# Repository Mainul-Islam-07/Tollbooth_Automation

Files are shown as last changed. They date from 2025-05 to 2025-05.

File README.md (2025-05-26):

#  🚧 Tollbooth_Automation
## ℹ️ Overview
Developed an automated tollbooth system capable of managing vehicle access efficiently, securely, and intelligently using a state machine–based control architecture.
The core logic is modeled as a finite state machine, enabling the system to transition between different operational modes depending on real-time triggers like camera input, payment status, vehicle movement, or override commands.
## 🌟 Highlights

### Microcontroller 💻
STM32F103C8t6 is used as the microcontroller.

### Ethernet Communication 🌐
Wiznet W5500 is used for Ethernet communication with the computer.

### UART Communication 🔄
Two UART communication interfaces (One of them is for debugging).

## ⚙️ Features 
### Vehicle Detection (Entry) 🚗
Detection of an approaching vehicle using inductive loop coils installed on the entry lane.

### Automated Boom Barrier Control 🚧
The boom barrier is raised or lowered based on toll payment status and vehicle position, ensuring only authorized passage.

### Vehicle Detection (Exit) 🚙
Detection of a car leaving the toll area is also handled via loop coils on the exit side.

### Car Exit Confirmation via IR Sensor 🌟
An IR sensor provides an additional check to confirm that the car has left the toll zone properly.

### Siren Control for Violations 🚨
A siren is triggered in case of illegal car passage (e.g., unpaid exit) and turned off after resolution or proper payment.

### TCU Breach Detection 🔒
The system monitors for unauthorized access or tampering with the Toll Controller Unit (TCU) and issues alerts on breach.

### Lane Operation Light Control 💡
The system manages lane indicator lights, guiding operators and drivers based on system state (e.g., red/green lights for status).

### Overhead Light Control 🌙
Overhead lighting at the booth is automatically controlled depending on operational mode or time of day.

### Additional Device Control (x3) ⚙️
Provision to control three additional AC or DC devices, configurable for future expansion (e.g., fan, display board, heater).

### PC Power Control (Upcoming) 💻
Planned feature to automatically turn the PC on/off based on toll activity or scheduled requirements. (Not yet implemented)

### Event Logging with External RTC (Upcoming) 🕰️
Future capability to log system events and state changes using a Real-Time Clock (RTC) module for time-stamped data. (Not yet implemented)

## Other Important aspects:

### Wiznet Interrupt-Based Communications 

### UART DMA Interrupt-Based Communication 

### Optocoupler-Based Input/Output for Isolation

### Encrypted Communication 🔐 (Not implemented yet)

## LED Board Config

Led Baord
 
## 🔁State Machine



## 🔧 Input/Output Circuit Diagram (Not Updated - Need Fix)

IO

## PCB Sample Image

TCU

## Proteus Simulation Sample (Not Updated - Need Fix)

abcde

# ICPS Header Connection between PCBs

Issues09

# Relay Board Pinout
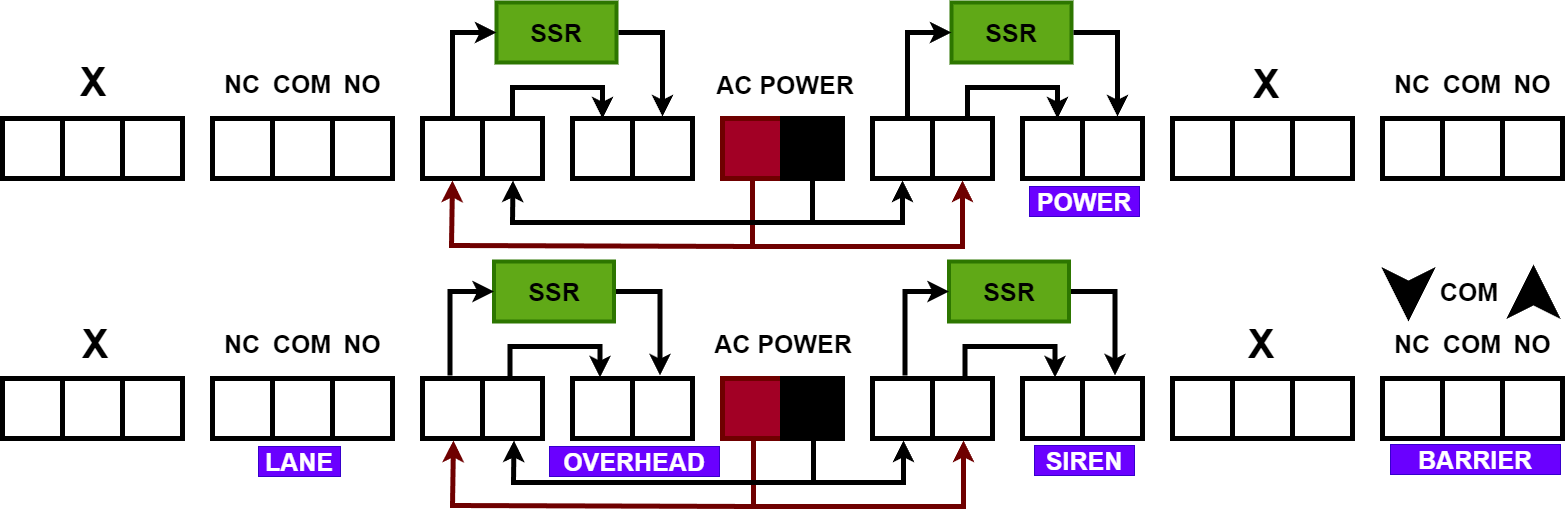
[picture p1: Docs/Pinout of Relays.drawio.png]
Relay Pinout


## ⬇️ Installation

Download and Install STM32CubeIDE from https://www.st.com/en/development-tools/stm32cubeide.html

Download and Install Hercules from https://www.hw-group.com/software/hercules-setup-utility

Download and Install Serial Debugger Assistant from https://apps.microsoft.com/detail/9nblggh43hdm?hl=en-US&gl=US

## Setup

1) Download the zip or fork and then clone to a local directory
2) Import the folder as a project in STM32CubeIde
3) Plug the mcu using st-link v2 where,

| MCU Pin (90° Bent) | Corresponding Pin on ST Link V2 |
|---|---|
| 3V3 (90 Degree Bent) | 3V3 |
| GND (90 Degree Bent) | GND |
| SWDIO (90 Degree Bent) | SWDIO |
| SCLK (90 Degree Bent)  | SCLK |

Like this,

Config

Then, plug the usb type A of ST-LINK V2 to Computer.

4) Press "Run" in the CubeIDE. Done!

# PCB PROBLEMS / SOLUTIONS / CONCERNS

2nd Iteration PCB is not finalized yet.

## TOLL CONTROLLER UNIT

1) SCLK And RST Connection from W5500 to MCU is manually swapped using wires. It should be fixed in next PCB design Iteration.
2) TX and RX connection from both UARTs is manually swapped using wires. The ususal way is UART TX > MCU TX and UART RX > MCU RX. To be fixed in the nextIteration.

Issues
Issues01

3) Since less current flow at Input, 1k ohm resistors attached at all of the 4 inputs in replaced by wire (shorting). Now the optocoupler responses any voltage from 6V. To be fixed in next iteration.
4) Voltage divider resistors are changed from 22k and 33k to 470 and 1k ohm for all inputs. It provides proper input to the mcu pins. To be fixed in next iteration.

Issues02
Issues03

5) All 470 ohm connected from MCU to Relay signal input side is manually shorted. This is done for proper signal sending. To be fixed in next iteration.
6) Voltage divider resistors are changed from 22k and 33k to 33k and 100k for All UART RX. To be fixed in the next iteration.
   
Issues04
Issues05

8) w5500 needs to be powered using a regulator from 5V to 3.3V. To be Fixed in next iteration.

## RELAY BOARD

1) The resistor after 470 ohm should not be used. It should be kept open. To be fixed in the next iteration.
2) A pullup of 10k is given from 12 volt to base of bc557 in such a way that it can be made 0V / 12V when needed. To be fixed in the next iteration.

Issues06
Issues07

3) Pulldown resistor is given of 100k ohm resistors.

Issues08

## LED BOARD

1) 1k ohm is connected to every signal end of mosfet used for powering RGB LED. Otherwise biasing issues emerge. To be fixed in the next iteration.
   
Issues09

2) Led that are powered by mcu directly should be equiped with less value resistor, lets say 100ohm. Applicable for Camera_Trigger, Payment and Ping LEDs.

# CODE PROBLEMS / SOLUTIONS / CONCERNS

1) Individual Flags for sensor update should be implemented in next iteration. 
2) CMD_NO_COMMAND should replace CMD_RESET as default outcome from processcommand.

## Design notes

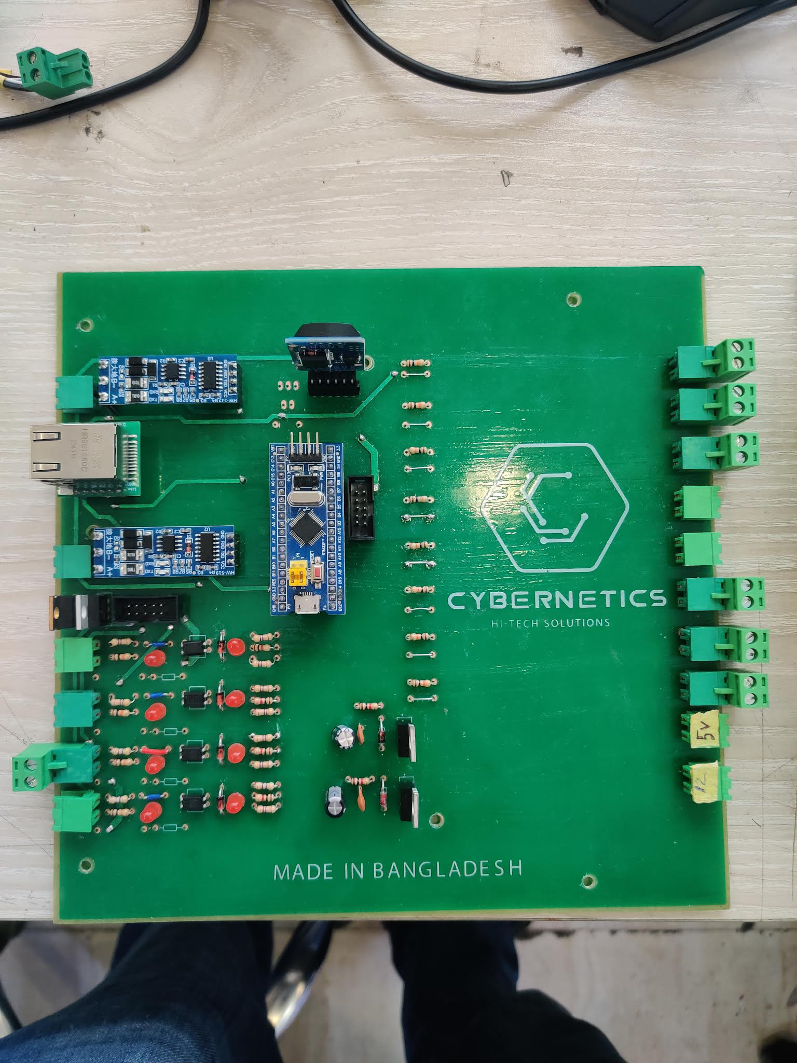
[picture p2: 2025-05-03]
Docs/TCU.jpg

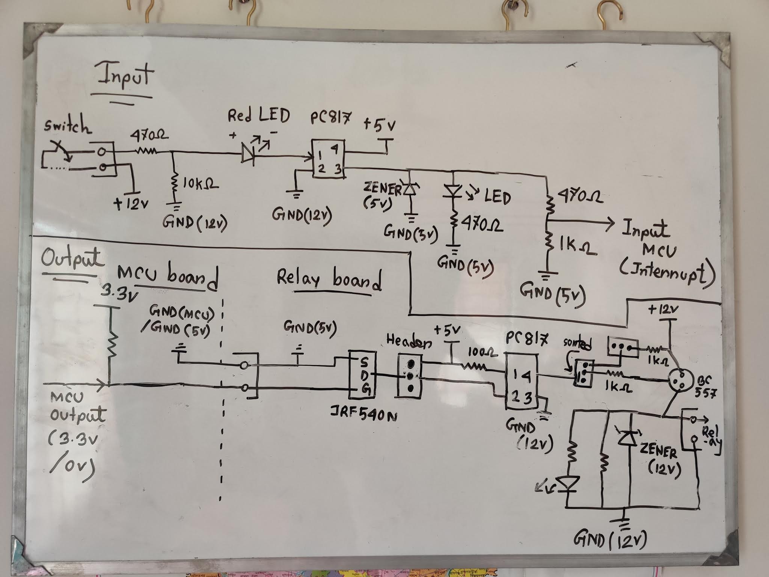
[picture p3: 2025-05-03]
Docs/IO.jpg

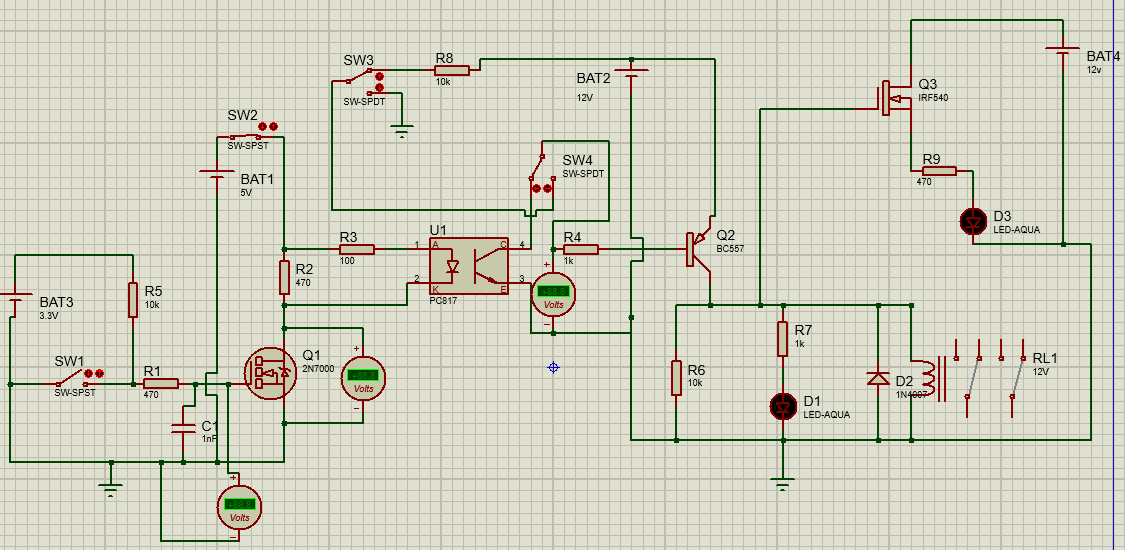
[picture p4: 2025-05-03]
Docs/Proteus Simlation.png

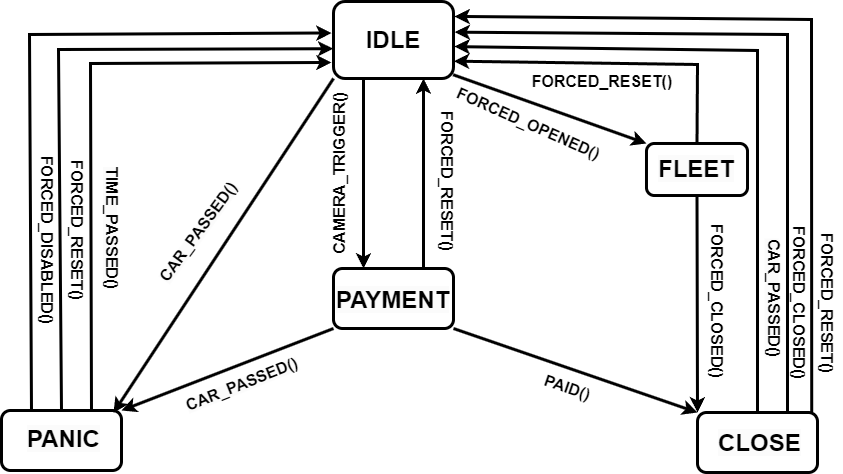
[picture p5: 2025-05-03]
State_Machine/State Diagram.png

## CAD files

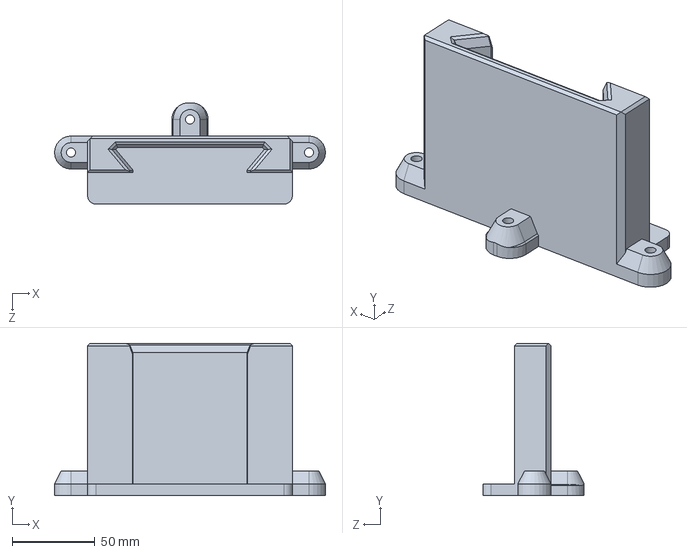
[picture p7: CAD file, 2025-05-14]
3D_Print/TCU LED board enclosure/Dove tail slot.SLDPRT
163.8 x 92.0 x 61.2 mm

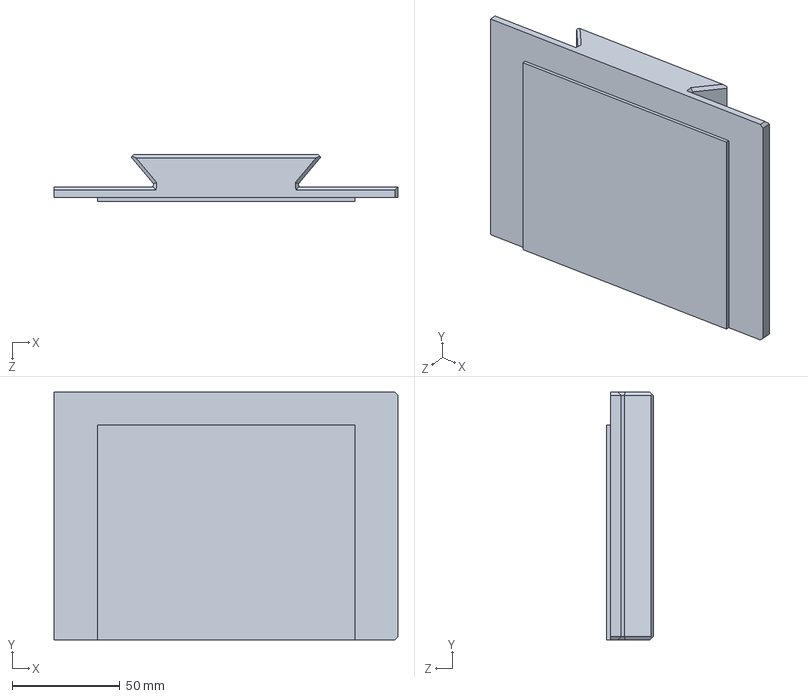
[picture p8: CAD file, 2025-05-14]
3D_Print/TCU LED board enclosure/Dove Tail.SLDPRT
159.7 x 115.0 x 21.7 mm

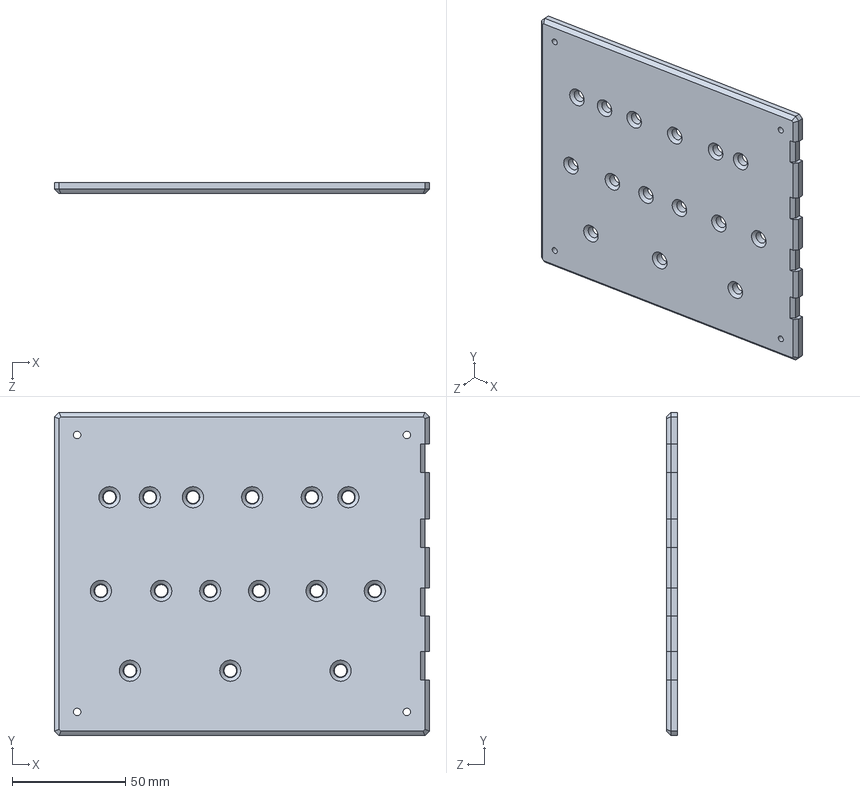
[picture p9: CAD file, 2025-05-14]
3D_Print/TCU LED board enclosure/Box top.SLDPRT
165.5 x 142.8 x 5.00 mm

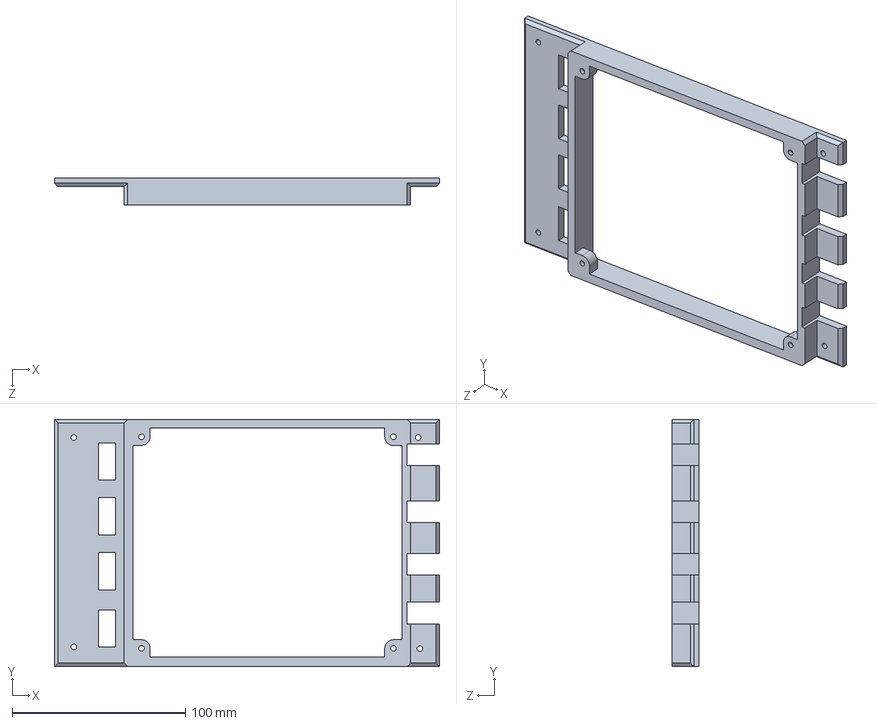
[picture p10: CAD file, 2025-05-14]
3D_Print/TCU LED board enclosure/Box Mid.SLDPRT
222.5 x 142.8 x 15.8 mm

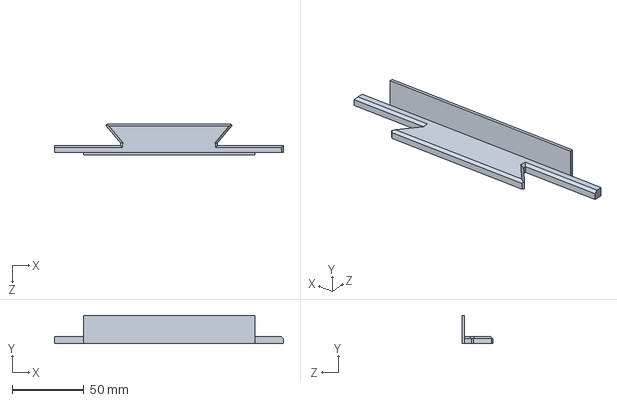
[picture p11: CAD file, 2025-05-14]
3D_Print/TCU LED board enclosure/Dove Tail mod.SLDPRT
159.7 x 19.7 x 21.7 mm

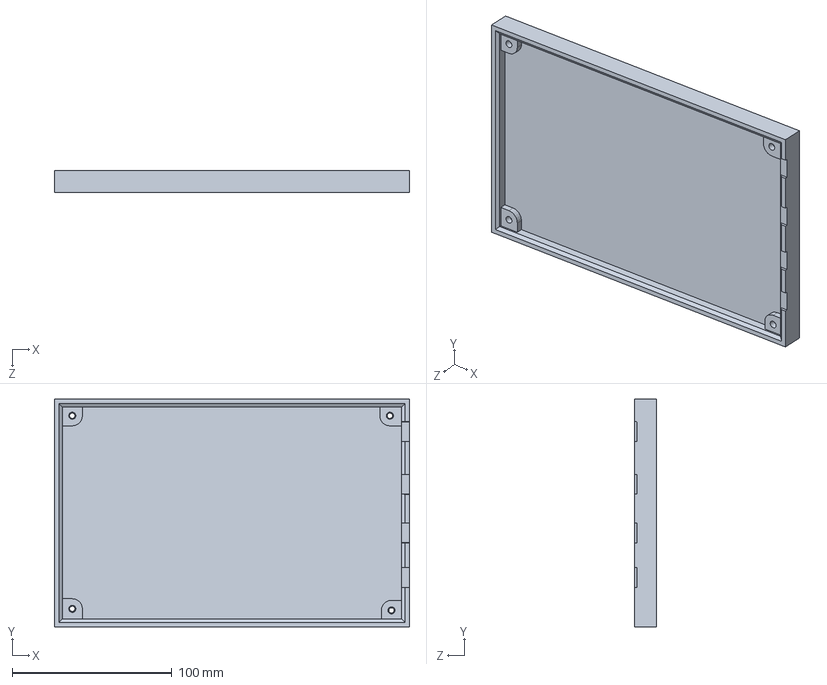
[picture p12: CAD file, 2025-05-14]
3D_Print/TCU LED board enclosure/Box base.SLDPRT
222.5 x 142.8 x 13.6 mm

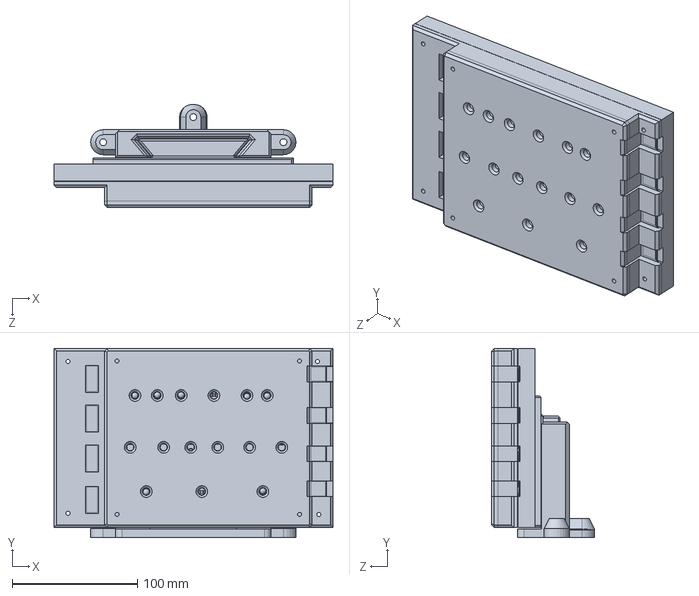
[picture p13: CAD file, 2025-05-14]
3D_Print/TCU LED board enclosure/LED_BOARD.SLDPRT
222.5 x 150.8 x 82.0 mm

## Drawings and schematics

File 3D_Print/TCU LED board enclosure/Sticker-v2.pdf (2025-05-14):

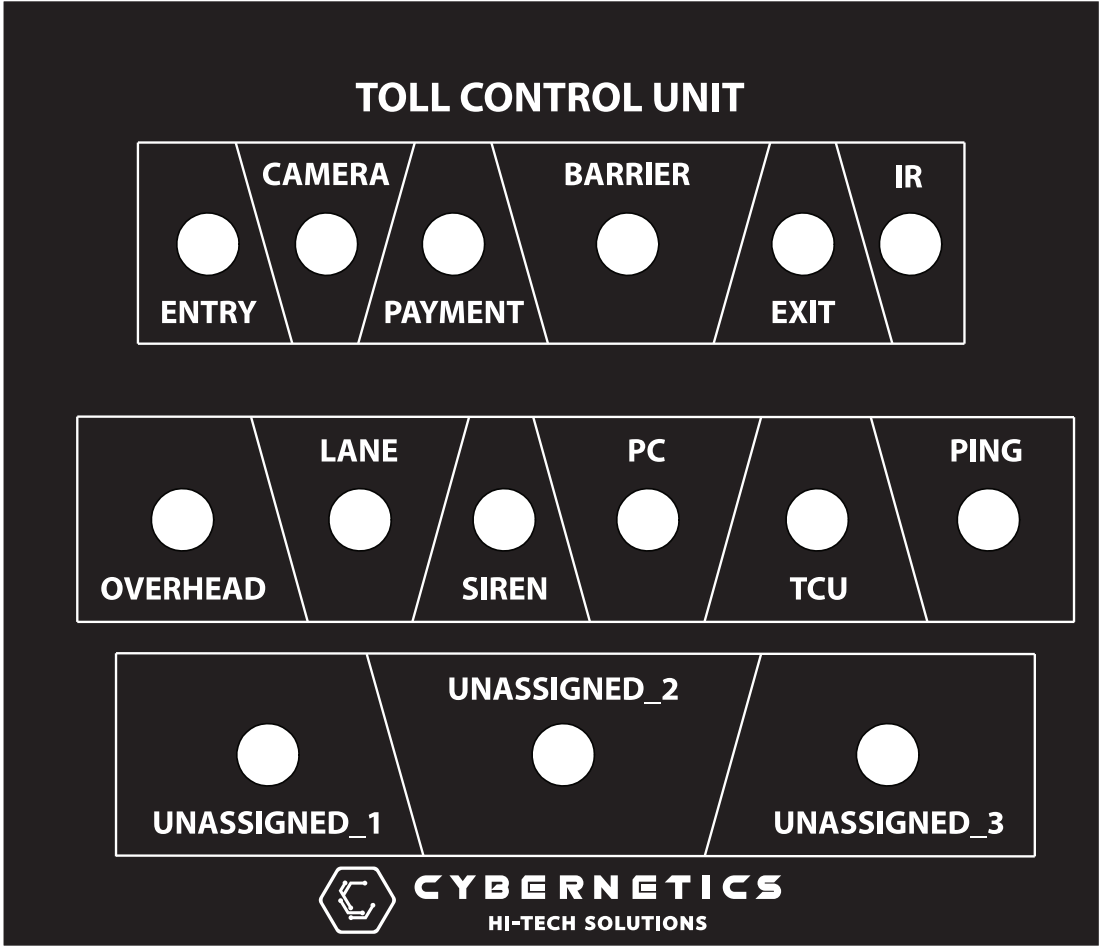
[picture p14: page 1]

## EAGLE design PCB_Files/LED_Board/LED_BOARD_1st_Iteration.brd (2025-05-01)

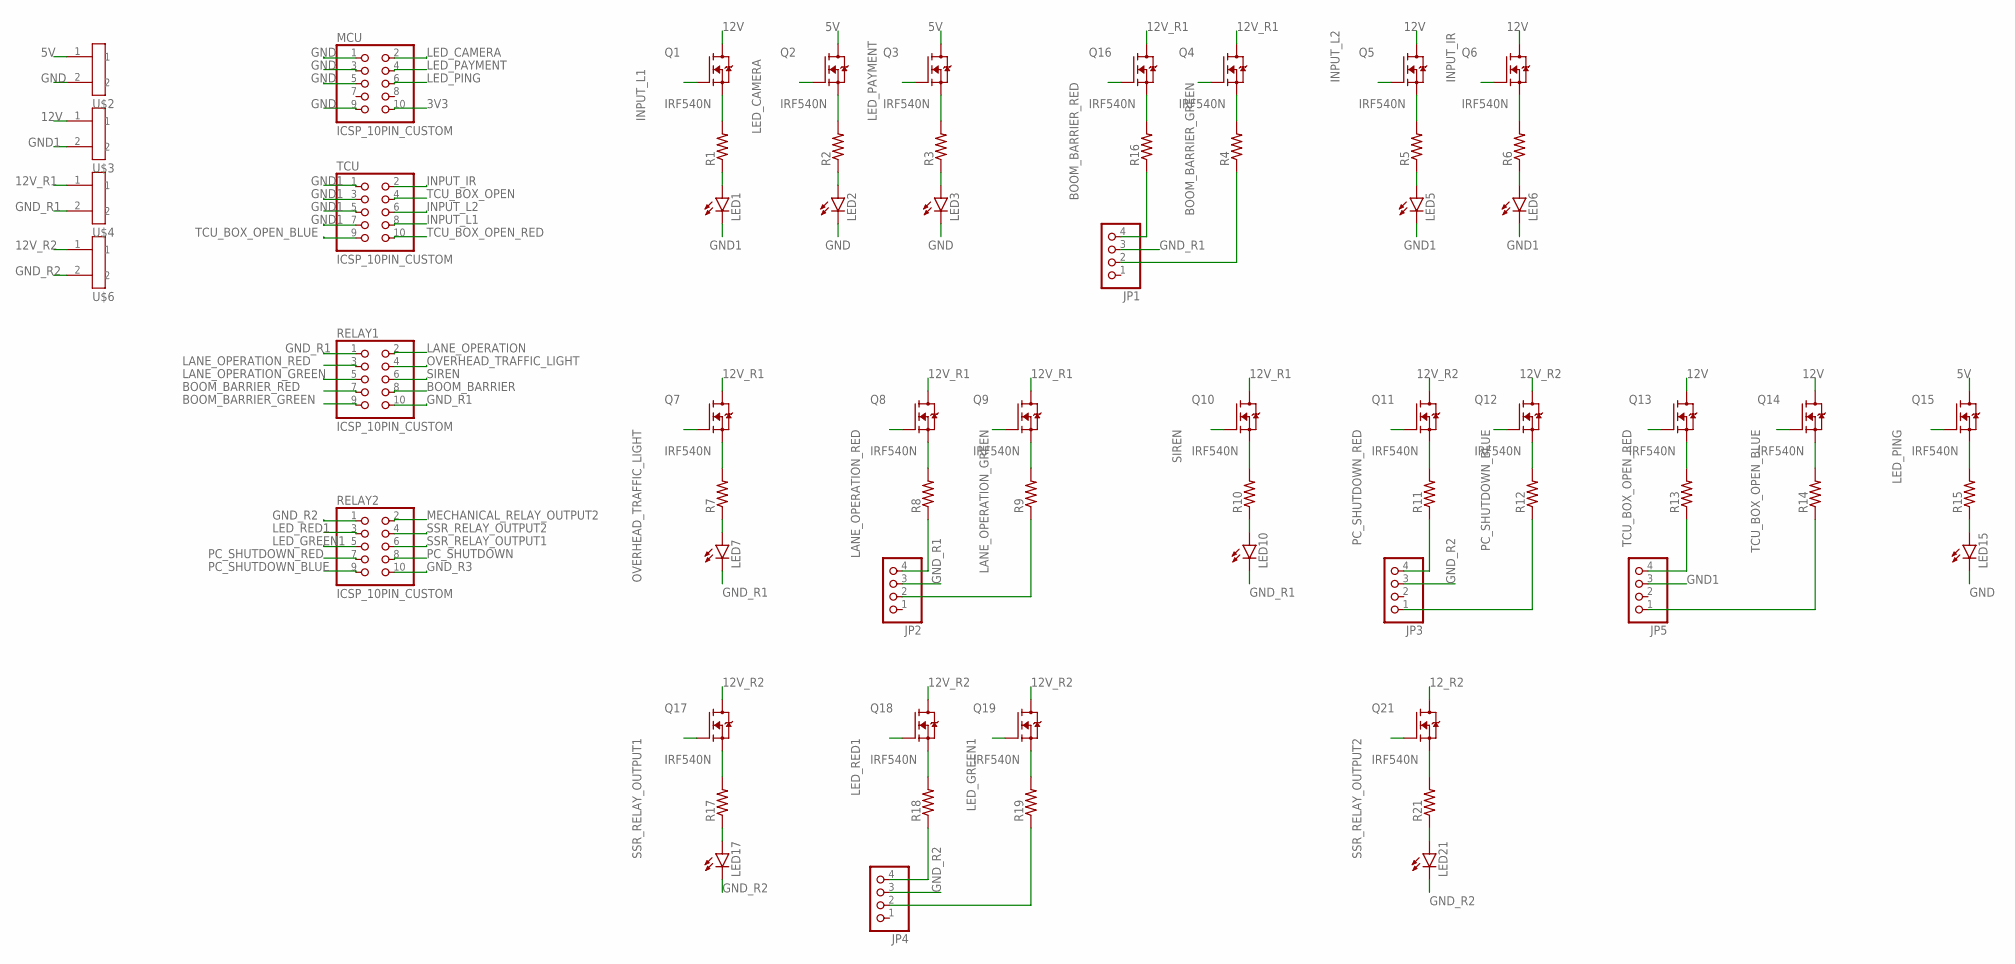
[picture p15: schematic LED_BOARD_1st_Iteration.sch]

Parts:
JP1, JP2, JP3, JP4, JP5: PINHD-1X4; 1X04
LED1, LED2, LED3, LED5, LED6, LED7, LED10, LED15, LED17, LED21: LED
MCU: ICSP_10PIN_CUSTOM
Q1, Q2, Q3, Q4, Q5, Q6, Q7, Q8, Q9, Q10, Q11, Q12, Q13, Q14, Q15, Q16, Q17, Q18, Q19, Q21: IRF540N; TO254P1054X469X1930-3
R1, R2, R3, R4, R5, R6, R7, R8, R9, R10, R11, R12, R13, R14, R15, R16, R17, R18, R19, R21: RESISTOR
RELAY1, RELAY2: ICSP_10PIN_CUSTOM
TCU: ICSP_10PIN_CUSTOM
U$2, U$3, U$4, U$6: GREEN_PLUG_90_2

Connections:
3V3: MCU.10
5V: Q2.2 (D), Q3.2 (D), Q15.2 (D), U$2.1
12V: Q1.2 (D), Q5.2 (D), Q6.2 (D), Q13.2 (D), Q14.2 (D), U$3.1
12V_R1: Q4.2 (D), Q7.2 (D), Q8.2 (D), Q9.2 (D), Q10.2 (D), Q16.2 (D), U$4.1
12V_R2: Q11.2 (D), Q12.2 (D), Q17.2 (D), Q18.2 (D), Q19.2 (D), U$6.1
12_R2: Q21.2 (D)
BOOM_BARRIER: RELAY1.8
BOOM_BARRIER_GREEN: Q4.1 (G), RELAY1.9
BOOM_BARRIER_RED: Q16.1 (G), RELAY1.7
GND: LED2.K (C), LED3.K (C), LED15.K (C), MCU.1, MCU.3, MCU.5, MCU.9, U$2.2
GND1: JP5.3, LED1.K (C), LED5.K (C), LED6.K (C), TCU.1, TCU.3, TCU.5, TCU.7, U$3.2
GND_R1: JP1.3, JP2.3, LED7.K (C), LED10.K (C), RELAY1.1, RELAY1.10, U$4.2
GND_R2: JP3.3, JP4.3, LED17.K (C), LED21.K (C), RELAY2.1, U$6.2
GND_R3: RELAY2.10
INPUT_IR: Q6.1 (G), TCU.2
INPUT_L1: Q1.1 (G), TCU.8
INPUT_L2: Q5.1 (G), TCU.6
LANE_OPERATION: RELAY1.2
LANE_OPERATION_GREEN: Q9.1 (G), RELAY1.5
LANE_OPERATION_RED: Q8.1 (G), RELAY1.3
LED_CAMERA: MCU.2, Q2.1 (G)
LED_GREEN1: Q19.1 (G), RELAY2.5
LED_PAYMENT: MCU.4, Q3.1 (G)
LED_PING: MCU.6, Q15.1 (G)
LED_RED1: Q18.1 (G), RELAY2.3
MECHANICAL_RELAY_OUTPUT2: RELAY2.2
unnamed: Q1.3 (S), R1.2
unnamed: LED1.A, R1.1
unnamed: JP1.4, R16.1
unnamed: JP1.2, R4.1
unnamed: JP2.4, R8.1
unnamed: Q2.3 (S), R2.2
unnamed: LED2.A, R2.1
unnamed: JP2.2, R9.1
unnamed: JP5.4, R13.1
unnamed: JP3.4, R11.1
unnamed: Q3.3 (S), R3.2
unnamed: LED3.A, R3.1
unnamed: JP3.1, R12.1
unnamed: JP5.1, R14.1
unnamed: Q4.3 (S), R4.2
unnamed: Q5.3 (S), R5.2
unnamed: LED5.A, R5.1
unnamed: Q6.3 (S), R6.2
unnamed: LED6.A, R6.1
unnamed: Q7.3 (S), R7.2
unnamed: LED7.A, R7.1
unnamed: Q8.3 (S), R8.2
unnamed: Q9.3 (S), R9.2
unnamed: Q10.3 (S), R10.2
unnamed: LED10.A, R10.1
unnamed: Q11.3 (S), R11.2
unnamed: Q12.3 (S), R12.2
unnamed: Q13.3 (S), R13.2
unnamed: Q14.3 (S), R14.2
unnamed: Q15.3 (S), R15.2
unnamed: LED15.A, R15.1
unnamed: Q16.3 (S), R16.2
unnamed: Q17.3 (S), R17.2
unnamed: LED17.A, R17.1
unnamed: Q18.3 (S), R18.2
unnamed: JP4.4, R18.1
unnamed: Q19.3 (S), R19.2
unnamed: JP4.2, R19.1
unnamed: Q21.3 (S), R21.2
unnamed: LED21.A, R21.1
OVERHEAD_TRAFFIC_LIGHT: Q7.1 (G), RELAY1.4
PC_SHUTDOWN: RELAY2.8
PC_SHUTDOWN_BLUE: Q12.1 (G), RELAY2.9
PC_SHUTDOWN_RED: Q11.1 (G), RELAY2.7
SIREN: Q10.1 (G), RELAY1.6
SSR_RELAY_OUTPUT1: Q17.1 (G), RELAY2.6
SSR_RELAY_OUTPUT2: Q21.1 (G), RELAY2.4
TCU_BOX_OPEN: TCU.4
TCU_BOX_OPEN_BLUE: Q14.1 (G), TCU.9
TCU_BOX_OPEN_RED: Q13.1 (G), TCU.10

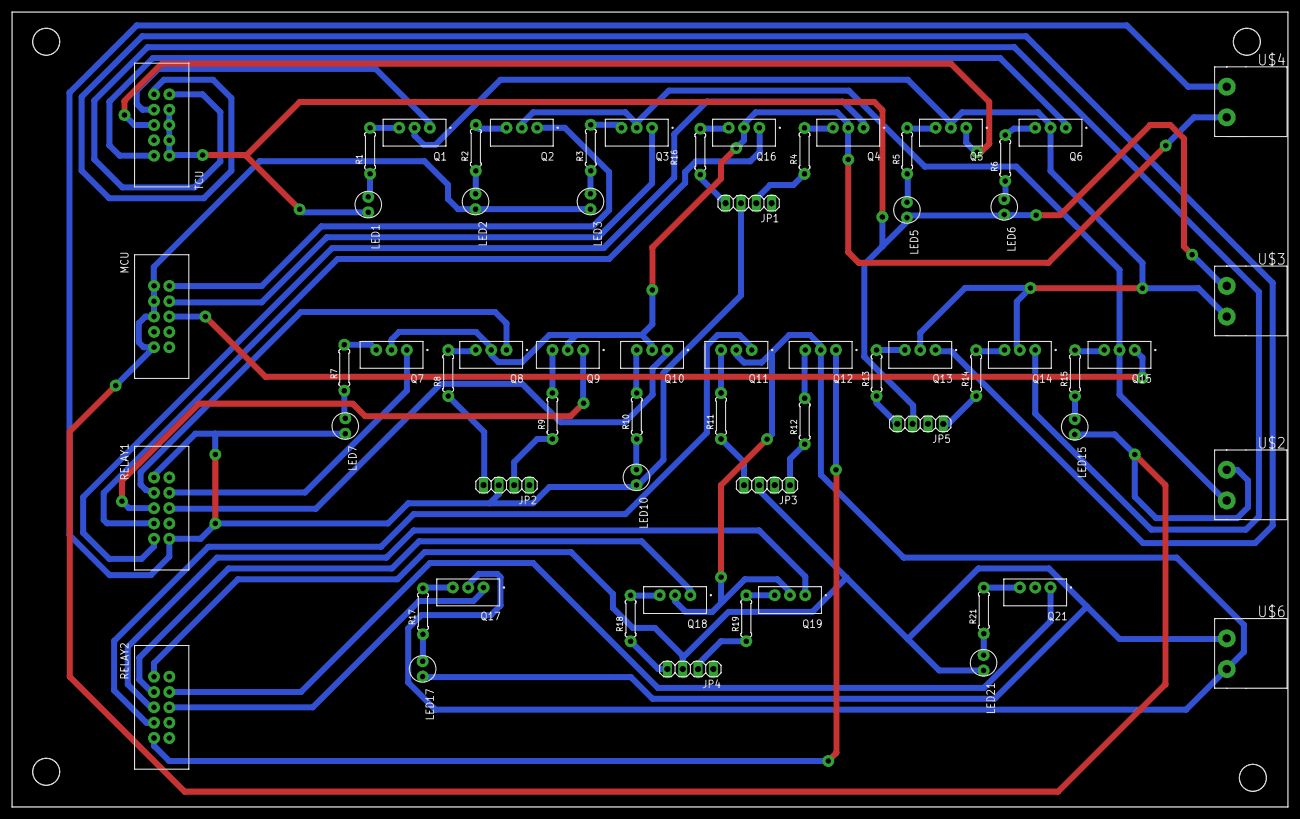
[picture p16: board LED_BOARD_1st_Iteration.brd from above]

Board: 2 copper layers, 211.5 x 131.8 mm, 63 parts (0 on the bottom side), 68 nets.

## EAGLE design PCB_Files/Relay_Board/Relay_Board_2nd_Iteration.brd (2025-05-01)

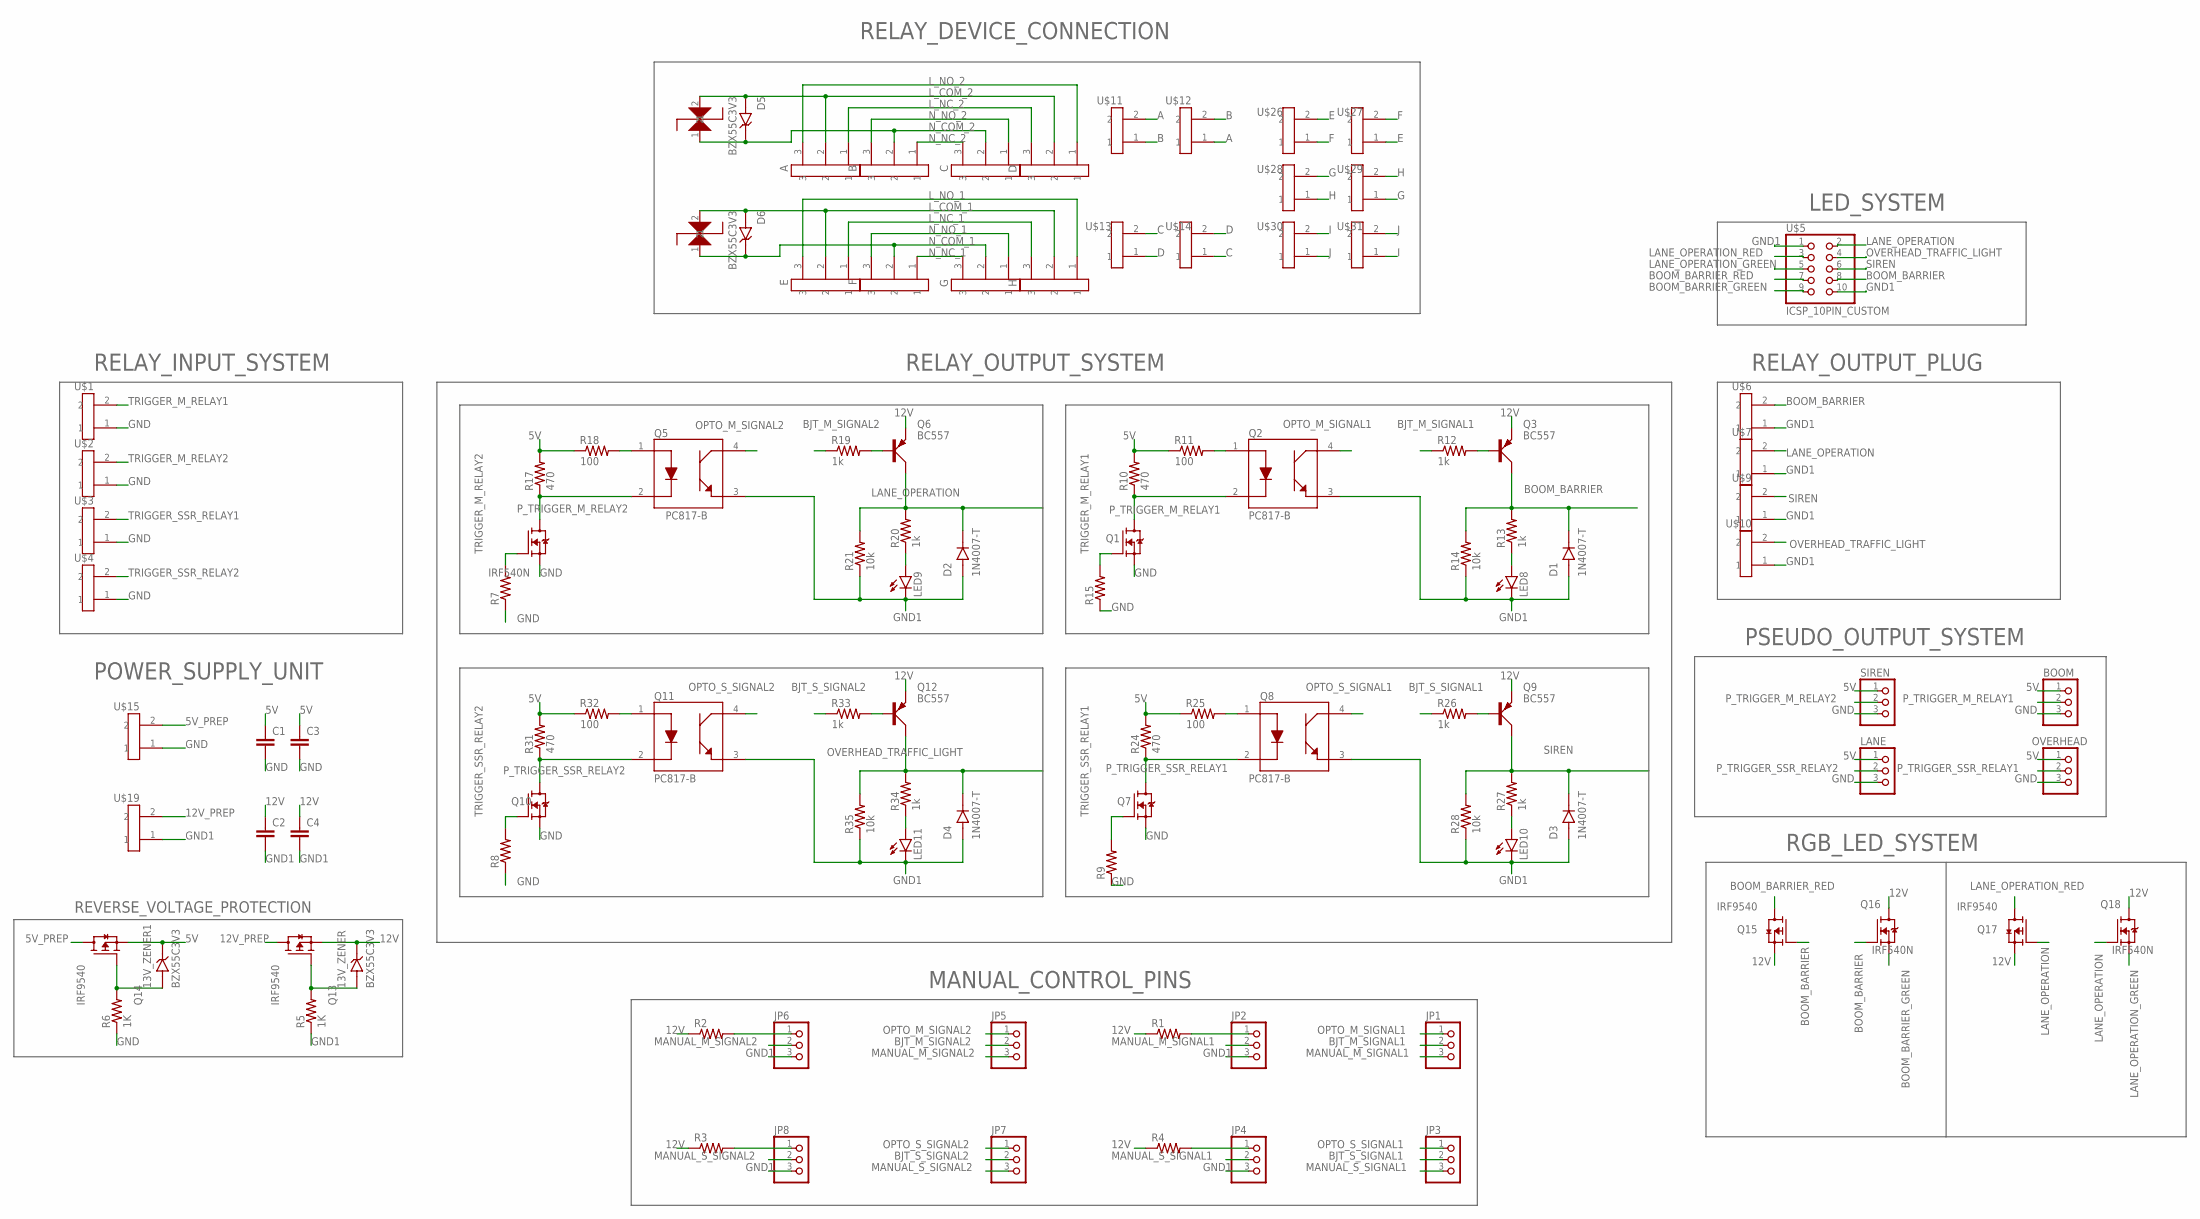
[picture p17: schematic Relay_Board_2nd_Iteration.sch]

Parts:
13V_ZENER, 13V_ZENER1: BZX55C3V3; DIOAD928W47L399D179
A: GREEN_PLUG_3
B: GREEN_PLUG_3
BOOM: PINHD-1X3; 1X03
C: GREEN_PLUG_90_3
C1, C2, C3, C4: CAPACITOR
D: GREEN_PLUG_90_3
D1, D2, D3, D4: 1N4007-T; DIOAD780W78L463D236
D5, D6: BZX55C3V3; DIOAD928W47L399D179
E: GREEN_PLUG_3
F: GREEN_PLUG_3
G: GREEN_PLUG_90_3
H: GREEN_PLUG_90_3
JP1, JP2, JP3, JP4, JP5, JP6, JP7, JP8: PINHD-1X3; 1X03
LANE: PINHD-1X3; 1X03
LED8, LED9, LED10, LED11: LED
OVERHEAD: PINHD-1X3; 1X03
Q1, Q4, Q7, Q10, Q16, Q18: IRF540N; TO254P1054X469X1930-3
Q2, Q5, Q8, Q11: PC817-B; DIP762W50P254L650H455Q4B
Q3, Q6, Q9, Q12: BC557; SOT54A
Q13, Q14, Q15, Q17: IRF9540; TO254P1052X465X1989-3
R1, R2, R3, R4, R7, R8, R9, R15: RESISTOR
R5, R6: 1K; RESISTOR
R10, R17, R24, R31: 470; RESISTOR
R11, R18, R25, R32: 100; RESISTOR
R12, R13, R19, R20, R26, R27, R33, R34: 1k; RESISTOR
R14, R21, R28, R35: 10k; RESISTOR
SIREN: PINHD-1X3; 1X03
U$1, U$2, U$3, U$4, U$12, U$13, U$15, U$19, U$27, U$29, U$31: GREEN_PLUG_90_2
U$5: ICSP_10PIN_CUSTOM
U$6, U$7, U$9, U$10, U$11, U$14, U$26, U$28, U$30: GREEN_PLUG_2
U$24, U$25: 1KE100A_CUSTOM

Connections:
5V: 13V_ZENER1.C (K), BOOM.1, C1.1, C3.1, LANE.1, OVERHEAD.1, Q14.3 (S), R10.2, R11.1, R17.2, R18.1, R24.2, R25.1, R31.2, R32.1, SIREN.1
5V_PREP: Q14.2 (D), U$15.2
12V: 13V_ZENER.C (K), C2.1, C4.1, Q3.E, Q6.E, Q9.E, Q12.E, Q13.3 (S), Q15.3 (S), Q16.2 (D), Q17.3 (S), Q18.2 (D), R1.1, R2.1, R3.1, R4.1
12V_PREP: Q13.2 (D), U$19.2
A: U$11.2, U$12.1
B: U$11.1, U$12.2
BJT_M_SIGNAL1: JP1.2, R12.1
BJT_M_SIGNAL2: JP5.2, R19.1
BJT_S_SIGNAL1: JP3.2, R26.1
BJT_S_SIGNAL2: JP7.2, R33.1
BOOM_BARRIER: D1.K, Q3.C, Q15.1 (G), Q16.1 (G), R13.2, R14.2, U$5.8, U$6.2
BOOM_BARRIER_GREEN: Q16.3 (S), U$5.9
BOOM_BARRIER_RED: Q15.2 (D), U$5.7
C: U$13.2, U$14.1
D: U$13.1, U$14.2
E: U$26.2, U$27.1
F: U$26.1, U$27.2
G: U$28.2, U$29.1
GND: BOOM.3, C1.2, C3.2, LANE.3, OVERHEAD.3, Q1.3 (S), Q4.3 (S), Q7.3 (S), Q10.3 (S), R6.1, R7.1, R8.1, R9.1, R15.1, SIREN.3, U$1.1, U$2.1, U$3.1, U$4.1, U$15.1
GND1: C2.2, C4.2, D1.A, D2.A, D3.A, D4.A, JP2.3, JP4.3, JP6.3, JP8.3, LED8.K (C), LED9.K (C), LED10.K (C), LED11.K (C), Q2.3 (EMITTER), Q5.3 (EMITTER), Q8.3 (EMITTER), Q11.3 (EMITTER), R5.1, R14.1, R21.1, R28.1, R35.1, U$5.1, U$5.10, U$6.1, U$7.1, U$9.1, U$10.1, U$19.1
H: U$28.1, U$29.2
I: U$30.2, U$31.1
J: U$30.1, U$31.2
LANE_OPERATION: D2.K, Q6.C, Q17.1 (G), Q18.1 (G), R20.2, R21.2, U$5.2, U$7.2
LANE_OPERATION_GREEN: Q18.3 (S), U$5.5
LANE_OPERATION_RED: Q17.2 (D), U$5.3
L_COM_1: D6.A, E.2, H.2, U$25.2
L_COM_2: A.2, D.2, D5.A, U$24.2
L_NC_1: E.1, H.3
L_NC_2: A.1, D.3
L_NO_1: E.3, H.1
L_NO_2: A.3, D.1
MANUAL_M_SIGNAL1: JP1.3, JP2.2
MANUAL_M_SIGNAL2: JP5.3, JP6.2
MANUAL_S_SIGNAL1: JP3.3, JP4.2
MANUAL_S_SIGNAL2: JP7.3, JP8.2
unnamed: 13V_ZENER1.A, Q14.1 (G), R6.2
unnamed: Q3.B, R12.2
unnamed: 13V_ZENER.A, Q13.1 (G), R5.2
unnamed: JP2.1, R1.2
unnamed: JP4.1, R4.2
unnamed: LED8.A, R13.1
unnamed: Q2.1 (ANODE), R11.2
unnamed: Q6.B, R19.2
unnamed: LED9.A, R20.1
unnamed: Q5.1 (ANODE), R18.2
unnamed: Q9.B, R26.2
unnamed: LED10.A, R27.1
unnamed: Q8.1 (ANODE), R25.2
unnamed: JP6.1, R2.2
unnamed: Q12.B, R33.2
unnamed: LED11.A, R34.1
unnamed: Q11.1 (ANODE), R32.2
unnamed: JP8.1, R3.2
N_COM_1: D6.C (K), F.2, G.2, U$25.1
N_COM_2: B.2, C.2, D5.C (K), U$24.1
N_NC_1: F.1, G.3
N_NC_2: B.1, C.3
N_NO_1: F.3, G.1
N_NO_2: B.3, C.1
OPTO_M_SIGNAL1: JP1.1, Q2.4 (COLLECTOR)
OPTO_M_SIGNAL2: JP5.1, Q5.4 (COLLECTOR)
OPTO_S_SIGNAL1: JP3.1, Q8.4 (COLLECTOR)
OPTO_S_SIGNAL2: JP7.1, Q11.4 (COLLECTOR)
OVERHEAD_TRAFFIC_LIGHT: D4.K, Q12.C, R34.2, R35.2, U$5.4, U$10.2
P_TRIGGER_M_RELAY1: BOOM.2, Q1.2 (D), Q2.2 (CATHODE), R10.1
P_TRIGGER_M_RELAY2: Q4.2 (D), Q5.2 (CATHODE), R17.1, SIREN.2
P_TRIGGER_SSR_RELAY1: OVERHEAD.2, Q7.2 (D), Q8.2 (CATHODE), R24.1
P_TRIGGER_SSR_RELAY2: LANE.2, Q10.2 (D), Q11.2 (CATHODE), R31.1
SIREN: D3.K, Q9.C, R27.2, R28.2, U$5.6, U$9.2
TRIGGER_M_RELAY1: Q1.1 (G), R15.2, U$1.2
TRIGGER_M_RELAY2: Q4.1 (G), R7.2, U$2.2
TRIGGER_SSR_RELAY1: Q7.1 (G), R9.2, U$3.2
TRIGGER_SSR_RELAY2: Q10.1 (G), R8.2, U$4.2

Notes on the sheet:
RELAY_OUTPUT_SYSTEM
RELAY_OUTPUT_PLUG
PSEUDO_OUTPUT_SYSTEM
RELAY_INPUT_SYSTEM
POWER_SUPPLY_UNIT
RELAY_DEVICE_CONNECTION
MANUAL_CONTROL_PINS
REVERSE_VOLTAGE_PROTECTION
RGB_LED_SYSTEM
LED_SYSTEM

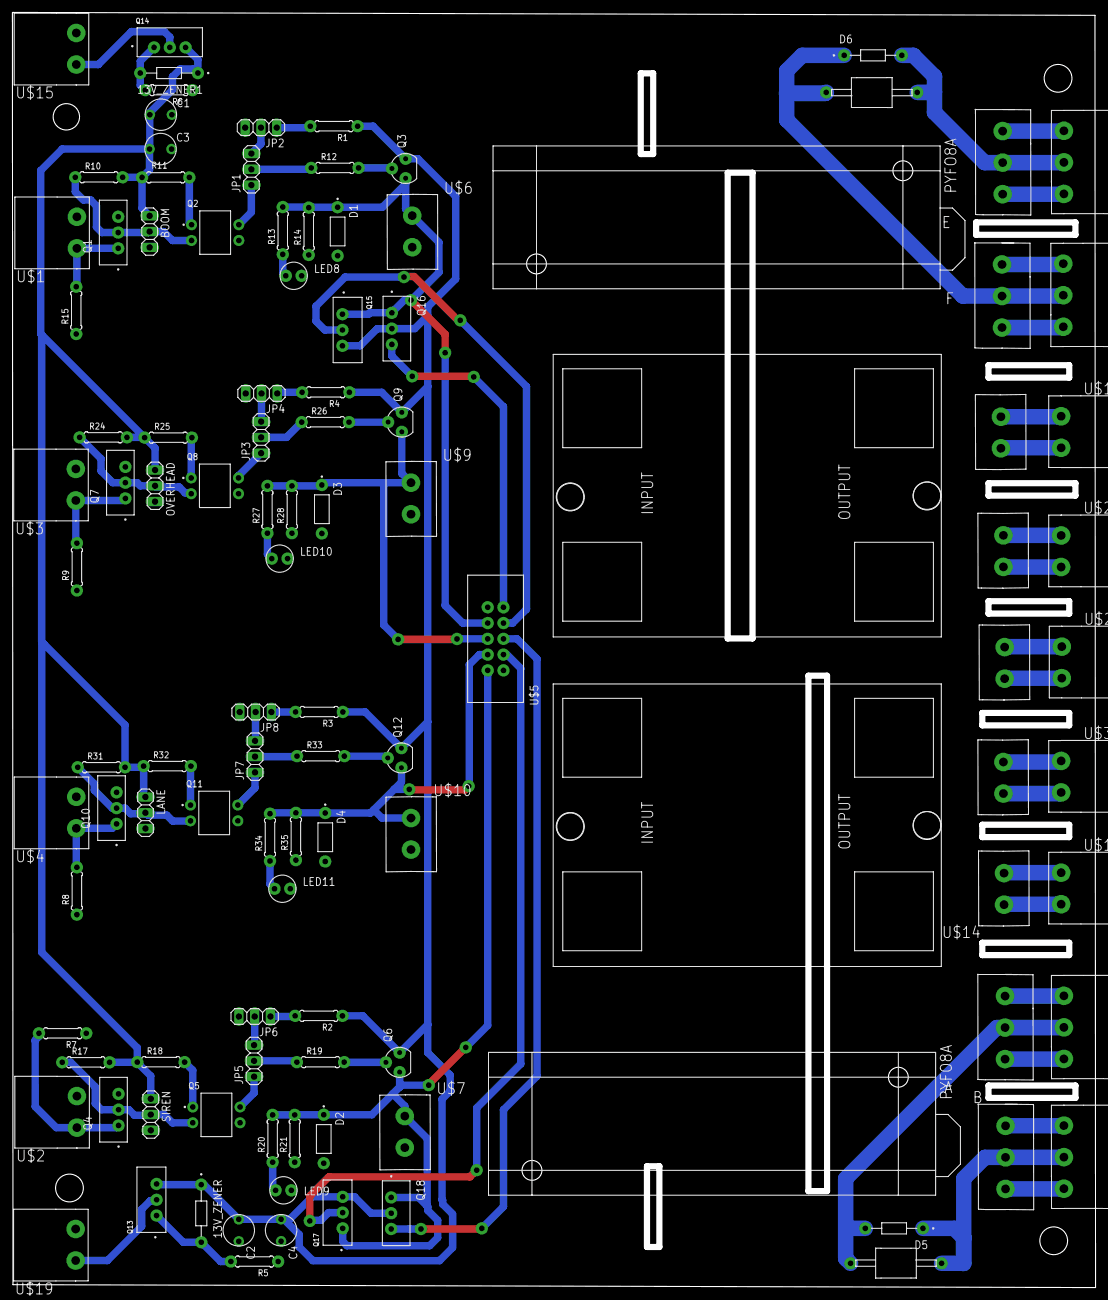
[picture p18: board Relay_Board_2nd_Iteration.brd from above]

Board: 2 copper layers, 174.4 x 205.3 mm, 111 parts (0 on the bottom side), 74 nets.

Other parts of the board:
U$8, U$16: PYF08A-E
U$17, U$18: SSR-40DASOLIDSTATERELAYMODULE

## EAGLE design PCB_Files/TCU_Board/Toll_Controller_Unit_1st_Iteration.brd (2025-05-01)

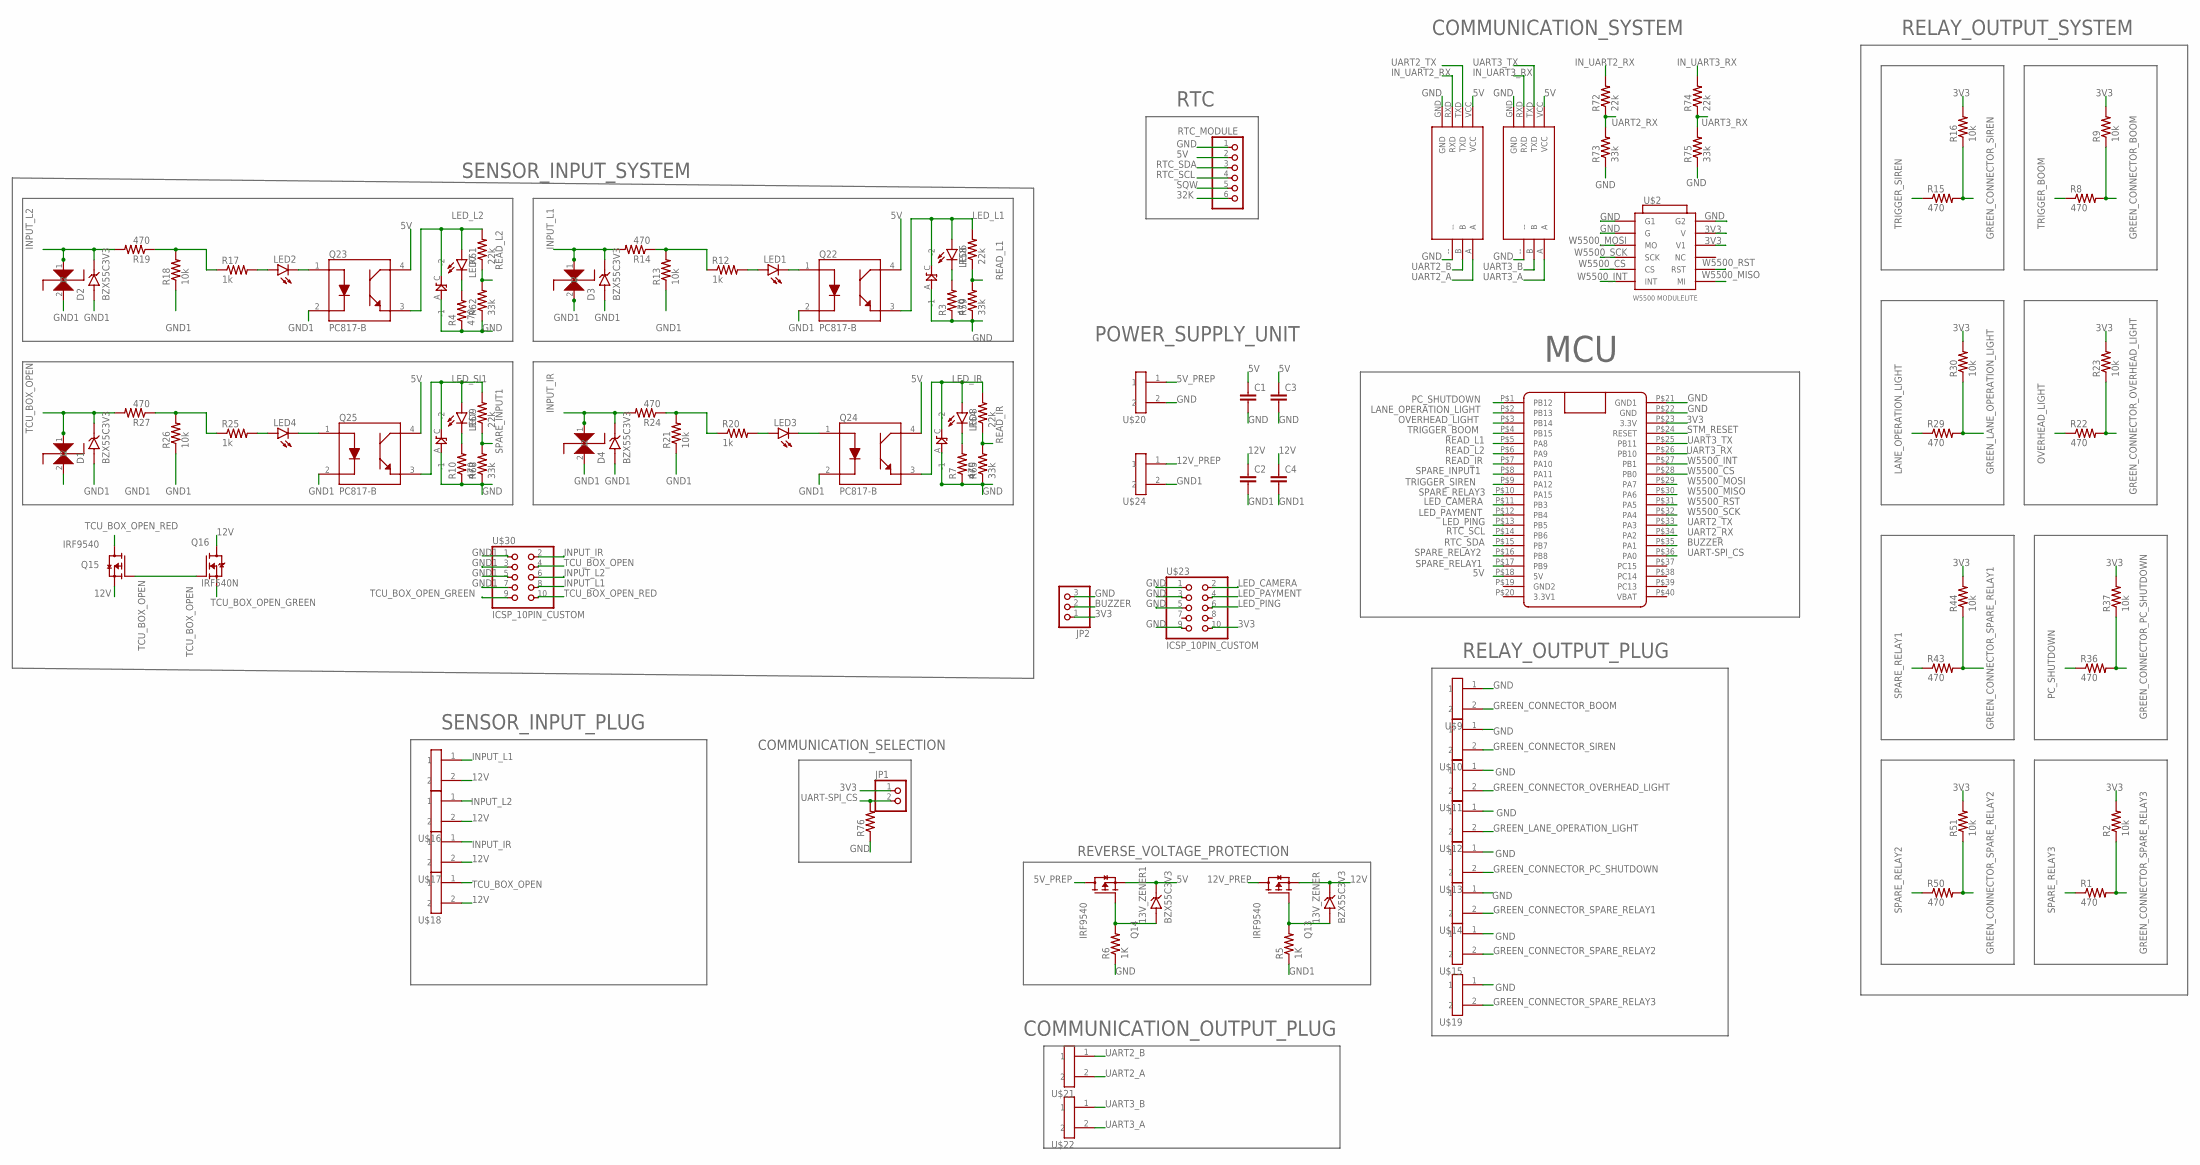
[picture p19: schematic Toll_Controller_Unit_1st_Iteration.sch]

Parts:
13V_ZENER, 13V_ZENER1: BZX55C3V3; DIOAD928W47L399D179
C1, C2, C3, C4: CAPACITOR
D1, D2, D3, D4: BZX55C3V3; DIOAD928W47L399D179
JP1: PINHD-1X2; 1X02
JP2: PINHD-1X3; 1X03
LED1, LED2, LED3, LED4, LED6, LED7, LED8, LED9: LED
Q13, Q14, Q15: IRF9540; TO254P1052X465X1989-3
Q16: IRF540N; TO254P1054X469X1930-3
Q22, Q23, Q24, Q25: PC817-B; DIP762W50P254L650H455Q4B
R1, R3, R4, R7, R8, R10, R14, R15, R19, R22, R24, R27, R29, R36, R43, R50: 470; RESISTOR
R2, R9, R13, R16, R18, R21, R23, R26, R30, R37, R44, R51: 10k; RESISTOR
R5, R6: 1K; RESISTOR
R12, R17, R20, R25: 1k; RESISTOR
R58, R61, R64, R67, R72, R74: 22k; RESISTOR
R59, R62, R65, R68, R73, R75: 33k; RESISTOR
R76: RESISTOR
RTC_MODULE: PINHD-1X6; 1X06
STM_BLUEPILL: BLUE_PILL
U$1, U$3, U$4, U$5: 1N227B
U$2: W5500_MODULELITE
U$6, U$9, U$10, U$11, U$12, U$13, U$14, U$15, U$16, U$17, U$18, U$19, U$20, U$21, U$22, U$24: GREEN_PLUG_90_2
U$7, U$8: RS485_CHINESE
U$23, U$30: ICSP_10PIN_CUSTOM
U$25, U$26, U$27, U$28: 1KE100A_CUSTOM

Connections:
3V3: JP1.1, JP2.1, R2.2, R9.2, R16.2, R23.2, R30.2, R37.2, R44.2, R51.2, STM_BLUEPILL.P$23 (3.3V), U$2.V, U$2.V1, U$23.10
5V: 13V_ZENER1.C (K), C1.1, C3.1, Q14.3 (S), Q22.4 (COLLECTOR), Q23.4 (COLLECTOR), Q24.4 (COLLECTOR), Q25.4 (COLLECTOR), RTC_MODULE.2, STM_BLUEPILL.P$18 (5V), U$7.VCC, U$8.VCC
5V_PREP: Q14.2 (D), U$20.1
12V: 13V_ZENER.C (K), C2.1, C4.1, Q13.3 (S), Q15.3 (S), Q16.2 (D), U$6.2, U$16.2, U$17.2, U$18.2
12V_PREP: Q13.2 (D), U$24.1
32K: RTC_MODULE.6
BUZZER: JP2.2, STM_BLUEPILL.P$35 (PA1)
GND: C1.2, C3.2, JP2.3, R3.1, R4.1, R6.1, R7.1, R10.1, R59.1, R62.1, R65.1, R68.1, R73.1, R75.1, R76.1, RTC_MODULE.1, STM_BLUEPILL.P$21 (GND1), STM_BLUEPILL.P$22 (GND), U$1.A (-1), U$2.G, U$2.G1, U$2.G2, U$3.A (-1), U$4.A (-1), U$5.A (-1), U$7.--, U$7.GND, U$8.--, U$8.GND, U$9.1, U$10.1, U$11.1, U$12.1, U$13.1, U$14.1, U$15.1, U$19.1, U$20.2, U$23.1, U$23.3, U$23.5, U$23.9
GND1: C2.2, C4.2, D1.A, D2.A, D3.A, D4.A, Q22.2 (CATHODE), Q23.2 (CATHODE), Q24.2 (CATHODE), Q25.2 (CATHODE), R5.1, R13.1, R18.1, R21.1, R26.1, U$24.2, U$25.2, U$26.2, U$30.1, U$30.3, U$30.5, U$30.7
GREEN_CONNECTOR_BOOM: R8.2, R9.1, U$9.2
GREEN_CONNECTOR_OVERHEAD_LIGHT: R22.2, R23.1, U$11.2
GREEN_CONNECTOR_PC_SHUTDOWN: R36.2, R37.1, U$13.2
GREEN_CONNECTOR_SIREN: R15.2, R16.1, U$10.2
GREEN_CONNECTOR_SPARE_RELAY1: R43.2, R44.1, U$14.2
GREEN_CONNECTOR_SPARE_RELAY2: R50.2, R51.1, U$15.2
GREEN_CONNECTOR_SPARE_RELAY3: R1.2, R2.1, U$19.2
GREEN_LANE_OPERATION_LIGHT: R29.2, R30.1, U$12.2
INPUT_IR: D4.C (K), R24.2, U$17.1, U$27.1, U$30.2
INPUT_L1: D3.C (K), R14.2, U$6.1, U$25.1, U$30.8
INPUT_L2: D2.C (K), R19.2, U$16.1, U$28.1, U$30.6
IN_UART2_RX: R72.2, U$8.RXD
IN_UART3_RX: R74.2, U$7.RXD
LANE_OPERATION_LIGHT: R29.1, STM_BLUEPILL.P$2 (PB13)
LED_CAMERA: STM_BLUEPILL.P$11 (PB3), U$23.2
LED_IR: LED8.A, Q24.3 (EMITTER), R64.2, U$4.C (-2)
LED_L1: LED6.A, Q22.3 (EMITTER), R58.2, U$1.C (-2)
LED_L2: LED7.A, Q23.3 (EMITTER), R61.2, U$3.C (-2)
LED_PAYMENT: STM_BLUEPILL.P$12 (PB4), U$23.4
LED_PING: STM_BLUEPILL.P$13 (PB5), U$23.6
LED_SI1: LED9.A, Q25.3 (EMITTER), R67.2, U$5.C (-2)
unnamed: 13V_ZENER1.A, Q14.1 (G), R6.2
unnamed: 13V_ZENER.A, Q13.1 (G), R5.2
unnamed: LED6.K (C), R3.2
unnamed: LED7.K (C), R4.2
unnamed: LED8.K (C), R7.2
unnamed: LED9.K (C), R10.2
unnamed: LED1.A, R12.2
unnamed: R12.1, R13.2, R14.1
unnamed: LED2.A, R17.2
unnamed: R17.1, R18.2, R19.1
unnamed: LED3.A, R20.2
unnamed: R20.1, R21.2, R24.1
unnamed: R25.1, R26.2, R27.1
unnamed: LED4.A, R25.2
unnamed: LED1.K (C), Q22.1 (ANODE)
unnamed: LED3.K (C), Q24.1 (ANODE)
unnamed: LED4.K (C), Q25.1 (ANODE)
unnamed: LED2.K (C), Q23.1 (ANODE)
OVERHEAD_LIGHT: R22.1, STM_BLUEPILL.P$3 (PB14)
PC_SHUTDOWN: R36.1, STM_BLUEPILL.P$1 (PB12)
READ_IR: R64.1, R65.2, STM_BLUEPILL.P$7 (PA10)
READ_L1: R58.1, R59.2, STM_BLUEPILL.P$5 (PA8)
READ_L2: R61.1, R62.2, STM_BLUEPILL.P$6 (PA9)
RTC_SCL: RTC_MODULE.4, STM_BLUEPILL.P$14 (PB6)
RTC_SDA: RTC_MODULE.3, STM_BLUEPILL.P$15 (PB7)
SPARE_INPUT1: R67.1, R68.2, STM_BLUEPILL.P$8 (PA11)
SPARE_RELAY1: R43.1, STM_BLUEPILL.P$17 (PB9)
SPARE_RELAY2: R50.1, STM_BLUEPILL.P$16 (PB8)
SPARE_RELAY3: R1.1, STM_BLUEPILL.P$10 (PA15)
SQW: RTC_MODULE.5
STM_RESET: STM_BLUEPILL.P$24 (RESET)
TCU_BOX_OPEN: D1.C (K), Q15.1 (G), Q16.1 (G), R27.2, U$18.1, U$26.1, U$30.4
TCU_BOX_OPEN_GREEN: Q16.3 (S), U$30.9
TCU_BOX_OPEN_RED: Q15.2 (D), U$30.10
TRIGGER_BOOM: R8.1, STM_BLUEPILL.P$4 (PB15)
TRIGGER_SIREN: R15.1, STM_BLUEPILL.P$9 (PA12)
UART2_A: U$8.A, U$21.2
UART2_B: U$8.B, U$21.1
UART2_RX: R72.1, R73.2, STM_BLUEPILL.P$34 (PA2)
UART2_TX: STM_BLUEPILL.P$33 (PA3), U$8.TXD
UART3_A: U$7.A, U$22.2
UART3_B: U$7.B, U$22.1
UART3_RX: R74.1, R75.2, STM_BLUEPILL.P$26 (PB10)
UART3_TX: STM_BLUEPILL.P$25 (PB11), U$7.TXD
UART-SPI_CS: JP1.2, R76.2, STM_BLUEPILL.P$36 (PA0)
W5500_CS: STM_BLUEPILL.P$28 (PB0), U$2.CS
W5500_INT: STM_BLUEPILL.P$27 (PB1), U$2.INT
W5500_MISO: STM_BLUEPILL.P$30 (PA6), U$2.MI
W5500_MOSI: STM_BLUEPILL.P$29 (PA7), U$2.MO
W5500_RST: STM_BLUEPILL.P$31 (PA5), U$2.RST
W5500_SCK: STM_BLUEPILL.P$32 (PA4), U$2.SCK

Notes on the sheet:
MCU
COMMUNICATION_SYSTEM
POWER_SUPPLY_UNIT
SENSOR_INPUT_SYSTEM
RELAY_OUTPUT_SYSTEM
RELAY_OUTPUT_PLUG
SENSOR_INPUT_PLUG
RTC
COMMUNICATION_OUTPUT_PLUG
COMMUNICATION_SELECTION
REVERSE_VOLTAGE_PROTECTION

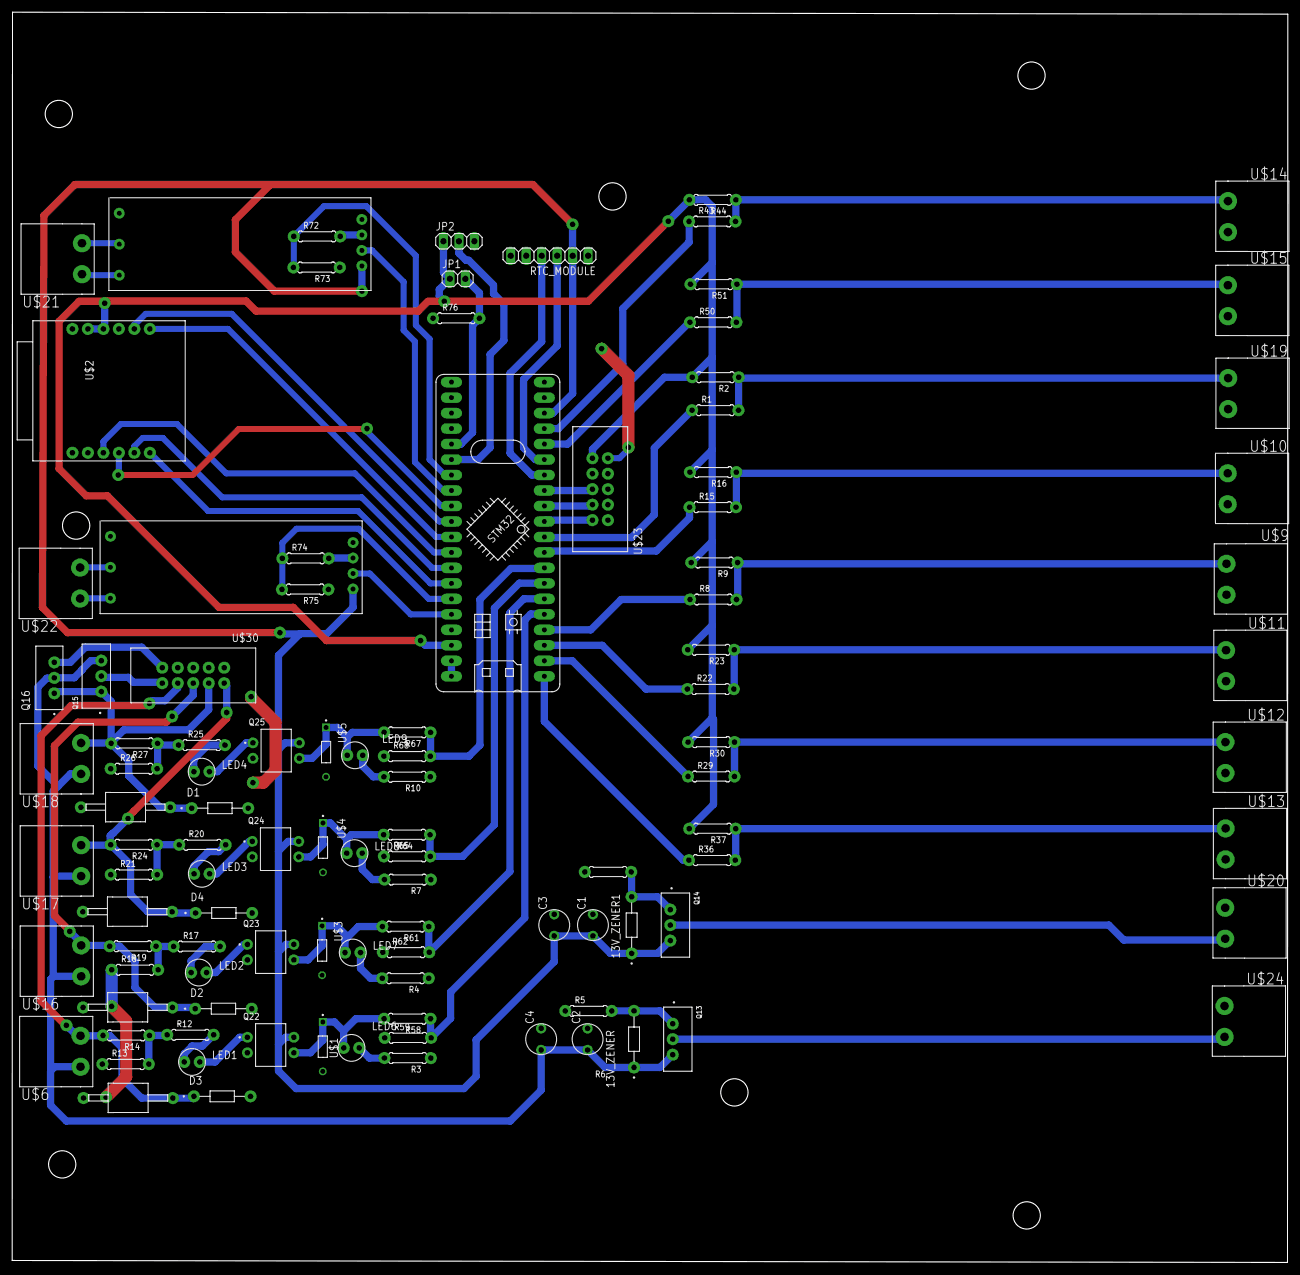
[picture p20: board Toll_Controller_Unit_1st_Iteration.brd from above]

Board: 2 copper layers, 209.3 x 205.1 mm, 106 parts (0 on the bottom side), 78 nets.

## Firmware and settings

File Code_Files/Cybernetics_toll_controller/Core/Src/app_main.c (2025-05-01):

/*
 * app_main.c
 *
 *  Created on: Mar 9, 2025
 *      Author: User
 */

#include "app_main.h"
#include "tcp_handler.h"



GlobalParam global;
Event_t event;

//uint32_t error;
W5500_GPIO_Config_t w5500_config = {
      .cs_port = W5500_CS_GPIO_Port,         // Replace with your CS GPIO port
      .cs_pin = W5500_CS_Pin,    // Replace with your CS GPIO pin
      .reset_port = W5500_RESET_GPIO_Port,      // Replace with your Reset GPIO port
      .reset_pin = W5500_RESET_Pin, // Replace with your Reset GPIO pin
      .int_port = W5500_INT_GPIO_Port,        // Replace with your Interrupt GPIO port
      .int_pin = W5500_INT_Pin,   // Replace with your Interrupt GPIO pin
      .spi_handle = &hspi1      // Replace with your SPI handle
  };


  wiz_NetInfo netInfo = {
      .mac = { 0x00, 0x08, 0xdc, 0xab, 0xcd, 0xef },
      .ip = { 192, 168, 20, 14 },
      .sn = { 255, 255, 255, 0 },
      .gw = { 192, 168, 20, 1 },
      .dns = { 8, 8, 8, 8 },
      .dhcp = NETINFO_STATIC
  };


void init(void){
	global.debug_uart 	 = &huart3;
	global.comm_uart  	 = &huart2;

//	global.loop1.port 	 = LOOP_COIL_1_GPIO_Port;
//	global.loop2.port 	 = LOOP_COIL_2_GPIO_Port;
//	global.ir.port 	  	 = IR_INPUT_GPIO_Port;
//	global.boom.port  	 = BOOM_BARRIER_GPIO_Port;
//	global.siren.port    = SIREN_GPIO_Port;
//
//	global.ledLoop1.port = LED_L1_GPIO_Port;
//	global.ledLoop2.port = LED_L2_GPIO_Port;
//	global.ledIr.port    = LED_IR_GPIO_Port;
//	global.ledBoom.port  = LED_BOOM_GPIO_Port;
//	global.ledSiren.port = LED_SIREN_GPIO_Port;
//
//	global.loop1.pin  	 = LOOP_COIL_1_Pin;
//	global.loop2.pin     = LOOP_COIL_2_Pin;
//	global.ir.pin 	     = IR_INPUT_Pin;
//	global.boom.pin      = BOOM_BARRIER_Pin;
//	global.siren.pin     = SIREN_Pin;
//
//	global.ledLoop1.pin  = LED_L1_Pin;
//	global.ledLoop2.pin  = LED_L2_Pin;
//	global.ledIr.pin	 = LED_IR_Pin;
//	global.ledBoom.pin   = LED_BOOM_Pin;
//	global.ledSiren.pin  = LED_SIREN_Pin;
//
//	global.gpioWrite = gpioWrite;
//
//	global.gpioRead = gpioRead;


	  HAL_Delay(1000);
	  startUartDMA(global.comm_uart);



	  //Initialize Wiznet w5500 with GPIOs, SPI and NetInfo
	  W5500Init(&w5500_config,&netInfo);


	  W5500_Init_Sockets();
	  rtcInit();
}


void loop(void){


	W5500_Handle_Events();
    event = generate_event(&sensorSystem, currentCommand, currentState);
    manualLedTrig(currentCommand);
    currentCommand = CMD_NOCOMMAND;
    updatePrevSensorState(&sensorSystem);
    run_state_machine(&currentState, event);
    state_Trigger(currentState);
    rtcDatafetch();
    connectionFeedback();

    //check_phy_status();
//    checkerror();

   // error = HAL_UART_GetError(&huart2);

   // global.gpioWrite(&global.loop1, SET);


}

//void gpioWrite(GPIOConfig_t *gpio, GPIO_PinState state) {
//    HAL_GPIO_WritePin(gpio->port, gpio->pin, state);
//}
//
//uint8_t gpioRead(GPIOConfig_t *gpio) {
//    return
//    HAL_GPIO_ReadPin(gpio->port, gpio->pin);
//}

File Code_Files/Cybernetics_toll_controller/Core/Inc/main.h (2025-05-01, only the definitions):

#define LD2_Pin GPIO_PIN_13
#define LD2_GPIO_Port GPIOC
#define LED_PING_Pin GPIO_PIN_5
#define LED_PING_GPIO_Port GPIOB
#define W5500_RESET_Pin GPIO_PIN_4
#define W5500_RESET_GPIO_Port GPIOA
#define W5500_CS_Pin GPIO_PIN_0
#define W5500_CS_GPIO_Port GPIOB
#define W5500_INT_Pin GPIO_PIN_1
#define W5500_INT_GPIO_Port GPIOB
#define W5500_INT_EXTI_IRQn EXTI1_IRQn
#define LANE_OPERATION_Pin GPIO_PIN_13
#define LANE_OPERATION_GPIO_Port GPIOB
#define OVERHEAD_LIGHT_Pin GPIO_PIN_14
#define OVERHEAD_LIGHT_GPIO_Port GPIOB
#define BOOM_BARRIER_Pin GPIO_PIN_15
#define BOOM_BARRIER_GPIO_Port GPIOB
#define ENTRYLOOP_COIL_Pin GPIO_PIN_8
#define ENTRYLOOP_COIL_GPIO_Port GPIOA
#define ENTRYLOOP_COIL_EXTI_IRQn EXTI9_5_IRQn
#define EXITLOOP_COIL_Pin GPIO_PIN_9
#define EXITLOOP_COIL_GPIO_Port GPIOA
#define EXITLOOP_COIL_EXTI_IRQn EXTI9_5_IRQn
#define IR_INPUT_Pin GPIO_PIN_10
#define IR_INPUT_GPIO_Port GPIOA
#define IR_INPUT_EXTI_IRQn EXTI15_10_IRQn
#define TCU_BOX_STATUS_Pin GPIO_PIN_11
#define TCU_BOX_STATUS_GPIO_Port GPIOA
#define TCU_BOX_STATUS_EXTI_IRQn EXTI15_10_IRQn
#define SIREN_Pin GPIO_PIN_12
#define SIREN_GPIO_Port GPIOA
#define LED_CAMERA_Pin GPIO_PIN_3
#define LED_CAMERA_GPIO_Port GPIOB
#define LED_PAYMENT_Pin GPIO_PIN_4
#define LED_PAYMENT_GPIO_Port GPIOB

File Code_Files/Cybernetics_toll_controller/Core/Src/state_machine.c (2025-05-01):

#include "state_machine.h"
#include "stm32f1xx_hal.h"
#include "Trigger.h"
#include "socket.h"
#include "tcp_handler.h"
#include "app_main.h"
#include "ISR_handler.h"


State_t currentState;
uint32_t stateTick = 0;
uint32_t panicTick = 0;
uint32_t connectTick = 0;
uint32_t cameraTick = 0;
uint32_t paidTick = 0;
uint32_t laneTick = 0;

volatile bool once = true;
// Individual state handlers
State_t handle_idle(Event_t evt) {
	once = true;
	#if (Mukhterpur == 1)
		switch (evt) {
		    case EVT_CAMERA_TRIGGER:    sendResponse(CMD_CAMERA_TRIGGER_RESP);   return STATE_PAYMENT;
			case EVT_ACTIVATE_SIREN: 	sendResponse(CMD_SIREN_ON); 		return STATE_PANIC;
			case EVT_FORCE_OPEN: 		sendResponse(CMD_BARRIER_OPEN); 	return STATE_FLEET;
			case EVT_SYSTEM_RESET: 									 		return STATE_IDLE;
			default: 					printState("STATE_IDLE");			return STATE_IDLE;

			}

	#else

		switch (evt) {
//Sensoer Based Events
			case EVT_CAR_DETECTED: 		sendResponse(CMD_VEHICLE_DETECTED); return STATE_PAYMENT; 	// Car Detection in 1st loop coil sensor
			case EVT_ACTIVATE_SIREN: 	sendResponse(CMD_SIREN_ON); 		return STATE_PANIC; 	// Car Passes without Payment (case which accounts 1st loop coil malfunction)
//Command Based Events
			case EVT_PAYMENT_COMPLETED: sendResponse(CMD_PAID_DONE); 		return STATE_WAIT_CAR;  // Forceful Payment completion (case which accounts for 1st loop coil malfunction)
			case EVT_FORCE_OPEN: 		sendResponse(CMD_BARRIER_OPEN); 	return STATE_FLEET; 	// Forceful Barrier opening
//			case EVT_FORCE_CLOSE: 		sendResponse(CMD_BARRIER_CLOSE);	return STATE_CLOSE;		// Forceful Barrier Closing   (case which accounts Boom Barrier Malfunction)
			default: 					printState("STATE_IDLE"); 			return STATE_IDLE;
			}

	#endif
}

State_t handle_payment(Event_t evt) {

	#if (Mukhterpur == 1)
		switch (evt) {
			case EVT_PAYMENT_COMPLETED: sendResponse(CMD_PAID_DONE);  		return STATE_CLOSE;
			case EVT_ACTIVATE_SIREN: 	sendResponse(CMD_SIREN_ON); 		return STATE_PANIC;
			case EVT_SYSTEM_RESET: 									 		return STATE_IDLE;
			default: 					printState("STATE_PAYMENT"); 		return STATE_PAYMENT;
		}
	#else
		switch (evt) {
//Sensoer Based Events
			case EVT_PAYMENT_COMPLETED: sendResponse(CMD_PAID_DONE); 		return STATE_WAIT_CAR;  // Payment Done
			case EVT_ACTIVATE_SIREN:	sendResponse(CMD_SIREN_ON);  		return STATE_PANIC;		// Car Passes without Payment
//Command Based Events
			case EVT_FORCE_OPEN:  		sendResponse(CMD_BARRIER_OPEN); 	return STATE_FLEET;		// Forceful Barrier opening
			case EVT_FORCE_CLOSE: 		sendResponse(CMD_BARRIER_CLOSE);	return STATE_CLOSE;		// Forceful Barrier Closing
//			case EVT_SIREN_OFF: 		sendResponse(CMD_SIREN_OFF);		return STATE_IDLE;		// Turning siren off (Starting from Beginning) (case which accounts siren malfunction)
			case EVT_SYSTEM_RESET: 		sendResponse(CMD_RESET_DONE); 		return STATE_IDLE;
			default: 					printState("STATE_PAYMENT"); 		return STATE_PAYMENT;
		}

	#endif
}

State_t handle_wait_car(Event_t evt) {

	#if (Mukhterpur == 1)
		switch (evt) {
			default: 					printState("STATE_WAIT_CAR");	    return STATE_WAIT_CAR;
		}

	#else
		switch (evt) {
//Sensoer Based Events
			case EVT_IR_CHECK: 												return STATE_CLOSE;		// Car passed 2nd loop coil sensor
//Command Based Events
//	        case EVT_DETECTION_FAIL: 										return STATE_CLOSE;		// Forceful state skip (case which accounts 2nd loop coil malfunction)
//	        case EVT_SIREN_OFF: 		sendResponse(CMD_SIREN_OFF);		return STATE_IDLE;		// Turning siren off (Starting from Beginning) (case which accounts siren malfunction)
			case EVT_SYSTEM_RESET: 		sendResponse(CMD_RESET_DONE); 		return STATE_IDLE;
			default: 					printState("STATE_WAIT_CAR");	    return STATE_WAIT_CAR;
		}

	#endif
}

State_t handle_fleet(Event_t evt) {
	#if (Mukhterpur == 1)
		switch (evt)
		{
			case EVT_FORCE_CLOSE:		sendResponse(CMD_BARRIER_CLOSE);	 return STATE_CLOSE;
			case EVT_SYSTEM_RESET: 									 		 return STATE_IDLE;
			default: 					printState("STATE_FLEET"); 			 return STATE_FLEET;
		}
	#else
		switch (evt) {
//Command Based Events
			case EVT_FORCE_CLOSE:		sendResponse(CMD_BARRIER_CLOSE);	 return STATE_CLOSE; // Forceful Barrier Closing
//	        case EVT_SIREN_OFF: 		sendResponse(CMD_SIREN_OFF);		 return STATE_IDLE;	 // Turning siren off (Starting from Beginning) (case which accounts siren malfunction)
			case EVT_SYSTEM_RESET: 		sendResponse(CMD_RESET_DONE); 		 return STATE_IDLE;
			default: 					printState("STATE_FLEET"); 			 return STATE_FLEET;
		}
	#endif
}
State_t handle_panic(Event_t evt) {
	#if (Mukhterpur == 1)
		switch (evt) {
			case EVT_SIREN_OFF: 			sendResponse(CMD_SIREN_OFF); 		return STATE_IDLE;
			case EVT_SYSTEM_RESET: 										 		return STATE_IDLE;
			default:
				while(once){
					panicTick = HAL_GetTick();
					once = false;
				}
				if (HAL_GetTick() - panicTick > 5000)
					{
						panicTick = HAL_GetTick();
						return STATE_IDLE;
					}
					else{
						printState("STATE_PANIC");
						return STATE_PANIC;
					}
		}
	#else
		switch (evt) {
//Command Based Events
			case EVT_FORCE_CLOSE: 		sendResponse(CMD_BARRIER_CLOSE); 	return STATE_CLOSE;	//Forceful Barrier Closing
			case EVT_SIREN_OFF:			sendResponse(CMD_SIREN_OFF); 		return STATE_IDLE;	// Turning siren off and Start from Beginning
			case EVT_SYSTEM_RESET: 		sendResponse(CMD_RESET_DONE); 		return STATE_IDLE;
			default: 					printState("STATE_PANIC"); 			return STATE_PANIC;

		}
	#endif
}

State_t handle_close(Event_t evt) {
	#if (Mukhterpur == 1)
		switch (evt) {
			case EVT_CAR_PASSED: 		sendResponse(CMD_BARRIER_CLOSE);	return STATE_IDLE;
			case EVT_SYSTEM_RESET: 									 		return STATE_IDLE;
			default: 					printState("STATE_CLOSE");			return STATE_CLOSE;
		}
	#else
		switch (evt) {
//Sensor Based Events
			case EVT_CAR_PASSED: 		sendResponse(CMD_BARRIER_CLOSE);	return STATE_IDLE;	// Car exited the Tollbooth safely
//Command Based Events
			case EVT_FORCE_CLOSE: 		sendResponse(CMD_BARRIER_CLOSE); 	return STATE_IDLE; 	// Forceful Barrier Closing
	//      case EVT_SIREN_OFF:  		sendResponse(CMD_SIREN_OFF); 		return STATE_IDLE;	// Turning siren off and Start from Beginning (case which accounts siren malfunction)
			default: 					printState("STATE_CLOSE");			return STATE_CLOSE;
		}
	#endif
	}

// Main event handler delegating to individual handlers
State_t handle_event(State_t current, Event_t evt) {

		switch (current) {
		case STATE_IDLE: 		return handle_idle(evt);
		case STATE_PAYMENT: 	return handle_payment(evt);
		case STATE_WAIT_CAR: 	return handle_wait_car(evt);
		case STATE_FLEET:		return handle_fleet(evt);
		case STATE_PANIC: 		return handle_panic(evt);
		case STATE_CLOSE: 		return handle_close(evt);
		default: 				return STATE_IDLE;
    }
}

const char* state_to_str(State_t state) {
    static const char* state_names[] = {"IDLE", "PAYMENT", "WAIT_CAR", "FLEET", "PANIC", "CLOSE"};
    return state_names[state];
}
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

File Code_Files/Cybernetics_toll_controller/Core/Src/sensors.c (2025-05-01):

#include "sensors.h"
#include "app_main.h"
#include "ISR_handler.h"

bool entryloopCoil_state = true;
bool exitloopCoil_state = true;
bool ir_state = true;


//// Global Sensor System
SensorSystem_t sensorSystem = {
    .entryloopCoil = {ENTRYLOOP_COIL, SENSOR_INACTIVE, SENSOR_INACTIVE, 0},
    .exitloopCoil = {EXITLOOP_COIL, SENSOR_INACTIVE, SENSOR_INACTIVE, 0},
    .irSensor = {IR_SENSOR, SENSOR_INACTIVE, SENSOR_INACTIVE, 0},
	.tcubox = {TCU_BOX_STATUS, SENSOR_INACTIVE, SENSOR_INACTIVE, 0}
};

// Function to update sensor state
void updateSensorState(SensorType_t sensorType, SensorSystem_t *sensors, SensorState_t state) {
    uint32_t currentTime = HAL_GetTick(); // Get system time in ms

    switch (sensorType) {
        case ENTRYLOOP_COIL:
            sensors->entryloopCoil.state = state;
            sensors->entryloopCoil.lastTriggered = currentTime;
            break;

        case EXITLOOP_COIL:
            sensors->exitloopCoil.state = state;
            sensors->exitloopCoil.lastTriggered = currentTime;
            break;

        case IR_SENSOR:
            sensors->irSensor.state = state;
            sensors->irSensor.lastTriggered = currentTime;
            break;

        case TCU_BOX_STATUS:
			sensors->tcubox.state = state;
			sensors->tcubox.lastTriggered = currentTime;
			break;

        default:
            break;
    }
}


void updatePrevSensorState(SensorSystem_t *sensors) {
	if(oneCycleIgnore == false)
	{
            sensors->entryloopCoil.prev_state = sensors->entryloopCoil.state;
            sensors->exitloopCoil.prev_state = sensors->exitloopCoil.state;
            sensors->irSensor.prev_state = sensors->irSensor.state;
            sensors->tcubox.prev_state = sensors->tcubox.state;
	}
}



void entryloopcoil_handler(void){

	if (HAL_GPIO_ReadPin(GPIOA, ENTRYLOOP_COIL_Pin) == GPIO_PIN_SET) {
		updateSensorState(ENTRYLOOP_COIL, &sensorSystem, SENSOR_ACTIVE);
	} else {
		updateSensorState(ENTRYLOOP_COIL, &sensorSystem, SENSOR_INACTIVE);
	}

//	if(entryloopCoil_state == true){
//		entryloopCoil_state = false;
//		HAL_NVIC_DisableIRQ(EXTI9_5_IRQn);
//		HAL_TIM_Base_Start_IT(&htim2);
//		HAL_GPIO_WritePin(LD2_GPIO_Port, LD2_Pin, SET);
//	}




}

void exitloopcoil_handler(void){

	if (HAL_GPIO_ReadPin(GPIOA, EXITLOOP_COIL_Pin) == GPIO_PIN_SET) {
			updateSensorState(EXITLOOP_COIL, &sensorSystem, SENSOR_ACTIVE);
		} else {
			updateSensorState(EXITLOOP_COIL, &sensorSystem, SENSOR_INACTIVE);
		}

//	if (exitloopCoil_state == true)
//	{
//		exitloopCoil_state = false;
//		HAL_NVIC_DisableIRQ(EXTI9_5_IRQn);
//		HAL_TIM_Base_Start_IT(&htim3);
//	}

}

void ir_handler(void){

	if (HAL_GPIO_ReadPin(GPIOA, IR_INPUT_Pin) == GPIO_PIN_SET) {
				updateSensorState(IR_SENSOR, &sensorSystem, SENSOR_ACTIVE);
			} else {
				updateSensorState(IR_SENSOR, &sensorSystem, SENSOR_INACTIVE);
			}
}

void tcubox_handler(void){

	if (HAL_GPIO_ReadPin(GPIOA, TCU_BOX_STATUS_Pin) == GPIO_PIN_SET) {
				updateSensorState(TCU_BOX_STATUS, &sensorSystem, SENSOR_ACTIVE);
			} else {
				updateSensorState(TCU_BOX_STATUS, &sensorSystem, SENSOR_INACTIVE);
			}
}


//	if(ir_state == true){
//		ir_state = false;
//		HAL_NVIC_DisableIRQ(EXTI15_10_IRQn);
//		HAL_TIM_Base_Start_IT(&htim4);
//	}




//// GPIO Interrupt Handler with Deactivation
//void HAL_GPIO_EXTI_Callback(uint16_t GPIO_Pin) {
//
//	if (GPIO_Pin == LOOP_COIL_1_Pin && entryloopCoil_state == true){
//		entryloopCoil_state = false;
//		HAL_NVIC_DisableIRQ(EXTI9_5_IRQn);
//		HAL_TIM_Base_Start_IT(&htim2);
//	}
//
//	if (GPIO_Pin == LOOP_COIL_2_Pin && exitloopCoil_state == true){
//		exitloopCoil_state = false;
//		HAL_NVIC_DisableIRQ(EXTI9_5_IRQn);
//		HAL_TIM_Base_Start_IT(&htim3);
//
//	}
//
//	if (GPIO_Pin == IR_INPUT_Pin && Ir_state == true){
//		Ir_state = false;
//		HAL_NVIC_DisableIRQ(EXTI15_10_IRQn);
//		HAL_TIM_Base_Start_IT(&htim4);
//	}
//}


//void HAL_TIM_PeriodElapsedCallback(TIM_HandleTypeDef *htim)
//{
//  /* Prevent unused argument(s) compilation warning */
//  UNUSED(htim);
//
//  if(htim->Instance == TIM2) {
//    if(HAL_GPIO_ReadPin(ENTRYLOOP_COIL_GPIO_Port, ENTRYLOOP_COIL_Pin) == GPIO_PIN_SET){
//    	updateSensorState(ENTRYLOOP_COIL, &sensorSystem, SENSOR_ACTIVE);
//		LED_Control(LED_L1, ON);
//	}
//    else {
//		updateSensorState(ENTRYLOOP_COIL, &sensorSystem, SENSOR_INACTIVE);
//		LED_Control(LED_L1, OFF);
//	}
//    entryloopCoil_state = true;
//    HAL_TIM_Base_Stop_IT(&htim2);
//
//    HAL_NVIC_EnableIRQ(EXTI9_5_IRQn);
//  }
//
//  else if(htim->Instance == TIM3) {
//    if(HAL_GPIO_ReadPin(EXITLOOP_COIL_GPIO_Port, EXITLOOP_COIL_Pin) == GPIO_PIN_SET){
//    	updateSensorState(EXITLOOP_COIL, &sensorSystem, SENSOR_ACTIVE);
//		LED_Control(LED_L2, ON);
//	}
//    else {
//		updateSensorState(EXITLOOP_COIL, &sensorSystem, SENSOR_INACTIVE);
//		LED_Control(LED_L2, OFF);
//	}
//    exitloopCoil_state = true;
//    HAL_TIM_Base_Stop_IT(&htim3);
//
//    HAL_NVIC_EnableIRQ(EXTI9_5_IRQn);
//  }
//
//  else if(htim->Instance == TIM4) {
//    if(HAL_GPIO_ReadPin(IR_INPUT_GPIO_Port, IR_INPUT_Pin) == GPIO_PIN_SET){
//    	updateSensorState(IR_SENSOR, &sensorSystem, SENSOR_ACTIVE);
//		LED_Control(LED_IR, ON);
//	} else {
//		updateSensorState(IR_SENSOR, &sensorSystem, SENSOR_INACTIVE);
//		LED_Control(LED_IR, OFF);
//	}
//    Ir_state = true;
//    HAL_TIM_Base_Stop_IT(&htim4);
//
//    HAL_NVIC_EnableIRQ(EXTI15_10_IRQn);
//  }
//
//  HAL_GPIO_WritePin(LD2_GPIO_Port, LD2_Pin, RESET);
//}

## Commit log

2025-05-01 Initial Commit & Normalize line endings and set binary handling
    [LED_BOARD_1st_Iteration.brd, LED_BOARD_1st_Iteration.sch, Relay_Board_1st_Iteration.brd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]
2025-05-03 Added State machine diagram, Proteus Simulation, PCB libraries
2025-05-03 Update README.md
    Added Relay board And LCD board issues
2025-05-03 Update README.md
    Update led board config, icsp header config, and setup process
2025-05-05 Replace CMD_RESET with CMD_NOCOMMAND
    [commands.c]
2025-05-14 Added 3d Printed parts of LED board
    [Box Mid.SLDPRT, Box base.SLDPRT, Box top.SLDPRT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]
2025-05-26 Added pinout of relays
2025-05-26 Update README.md
    Added relay pinout

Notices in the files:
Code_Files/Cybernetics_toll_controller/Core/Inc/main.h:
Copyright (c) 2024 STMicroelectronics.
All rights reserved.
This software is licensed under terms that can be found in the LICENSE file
